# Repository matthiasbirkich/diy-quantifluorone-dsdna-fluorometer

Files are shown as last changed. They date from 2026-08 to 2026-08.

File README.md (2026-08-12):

## eDNA Workshop 2026 — Start Here

**Workshop participants:** 
You do not need to navigate the repository structure to get started.

### Start the Workshop

➡️ **[Start the Workshop](docs/markdown/SUMMARY.md)**

The online documentation guides you step by step through the workshop,
from the introduction and instrument assembly to software installation,
calibration, dsDNA measurement, quality control, and troubleshooting.
For sequential reading, use the chapter navigation provided in the
documentation.

### 📘 Complete Workshop Booklet

The complete workshop documentation is also available as a PDF for

offline use, printing, or download:

➡️ **[Download the complete Workshop Booklet (PDF)](00_DIY-QuantiFluorONE_Workshop_Handbook.pdf)**

The PDF is approximately 30 MB and may not be previewed directly by GitHub.

Downloading the file is therefore recommended.

### Repository contents

The folders in this repository contain the hardware files, software,
Calibration Suite, validation data, references, and editable documentation
used to reproduce the project.

The workshop booklet is the primary guide for assembly, software installation,
basic operation, calibration, quality control, dsDNA measurement, validation,
and troubleshooting.

It guides participants through:

1. instrument overview and measurement principle;
2. safety and laboratory preparation;
3. hardware and assembly;
4. software installation;
5. basic operation and menu navigation;
6. calibration and data transfer;
7. dsDNA measurement;
8. calibration, results, and quality control;
9. validation and analytical performance; and
10. troubleshooting and workshop review.

The folders in this repository contain the source files, hardware documentation,
software, calibration tools, validation data, references, and editable workshop
documentation used to reproduce the project.

## About the project

The **DIY-QuantiFluorONE-dsDNA-Fluorometer**, abbreviated **DIY-QFO**, is an
independently developed portable fluorometer for fluorometric quantification
of double-stranded DNA (**dsDNA**).

The instrument is designed for use with the **Promega QuantiFluor® ONE dsDNA
System** and combines:

- an **Adafruit PyBadge** as controller, display, and user interface;
- one **TSL2591** fluorescence sensor positioned at 90° to the excitation axis;
- an **ioRodeo fixed-current radial 16 mA LED board**;
- a 485 nm excitation LED;
- Neemoo Ex470BP-40 and Em532BP-40 optical band-pass filters;
- a modified 3D-printed optical sample holder derived from concepts used by
  **DIYNAFLUOR** and the **ioRodeo fluorometer tube-holder project**; and
- modified firmware derived from the open-source **ioRodeo Open Colorimeter
  Plus** project.

The modular optical design allows LEDs, filters, sample holders, and detector
settings to be adapted for other fluorescence-based analytical applications,
provided that the modified configuration is appropriately calibrated and
evaluated.

## Citation and archived release

The archived release associated with the Open Validation work is:

**DIY-QuantiFluorONE-dsDNA-Fluorometer v1.0.3**  
Zenodo DOI: https://doi.org/10.5281/zenodo.21909959

The associated methodological preprint is:

**Birkicht, M. (2026). Beyond the Black Box: From Open Hardware to Open Validation in Analytical Science.**  
Zenodo DOI: https://doi.org/10.5281/zenodo.21910043

## Workshop context

This repository and the accompanying workshop booklet were prepared for the
**eDNA Workshop 2026** within the **STABLE Project (2025–2027), Higher
Education Partnership for a Sustainable Blue Economy**.

The workshop uses the DIY-QFO as an open and reproducible platform for
introducing fluorometric dsDNA quantification, instrument construction,
calibration, quality control, and analytical evaluation.

The instrument is intended for **research, teaching, development, and workshop
measurements**. It is not intended for clinical diagnostic use.

## Documentation

The complete workshop documentation is available in several forms:

- **Workshop Booklet (PDF)** — primary document for workshop participants;
- `workshop_booklet/` — Quarto source used to generate the booklet;
- `docs/` — project documentation and figures;
- `references/` — bibliography and project source/provenance records.

For workshop participation, the PDF booklet is the recommended starting point.
Participants do not need to navigate the complete repository during the
practical exercises.

## Repository map

The principal project directories are:

- **`bom/`** — bill of materials and component information;
- **`docs/`** — project documentation and figures;
- **`hardware/`** — mechanical CAD models, PCB files, wiring information, and
  hardware documentation;
- **`references/`** — bibliography and source/provenance records;
- **`software/`** — PyBadge bootloader, CircuitPython, and the supported
  QuantiFluorONE firmware release;
- **`tools/`** — Calibration Suite and supporting analytical utilities;
- **`validation/`** — analytical validation datasets, processed data, and
  evaluation scripts;
- **`workshop_booklet/`** — Quarto sources for the workshop booklet.

This structure separates hardware, software, analytical tools, validation
evidence, references, and documentation while maintaining traceability between
the documented instrument and the files required to reproduce it.

## Optical architecture

The DIY-QFO uses one TSL2591 fluorescence sensor positioned **at 90°** to the
excitation axis.

The documented configuration uses:

- 485 nm excitation LED;
- Neemoo Ex470BP-40, 8 × 8 × 1 mm excitation filter;
- Neemoo Em532BP-40, 8 × 8 × 1 mm emission filter; and
- Promega E4941 thin-walled 0.5 mL PCR tubes.

Fluorescence emitted by the stained dsDNA sample passes through the emission
filter and is detected by the TSL2591.

The project-defined visible analytical signal is:

\[
VIS = FULL - IR
\]

and the blank-corrected fluorescence response is used for calibration and
concentration calculation.

## Calibration and analytical performance

The firmware supports an on-instrument two-point calibration and import of a
compatible multipoint calibration.

Routine operation uses a two-point calibration consisting of a reagent blank
and a nominal 400 ng/µL lambda-DNA standard.

Under the tested configuration and assay conditions, method performance was
evaluated over an operational range of:

**0–400 ng/µL dsDNA**

The validation study showed close agreement with a Promega Quantus Fluorometer
used as an independent external comparator.

The project currently uses approximately:

- **LOD: 8 ng/µL**
- **LOQ: 24 ng/µL**

on the original-sample concentration basis.

Detailed calibration procedures, quality-control requirements, statistical
evaluation, validation results, and limitations are documented in the workshop
booklet and under `validation/`.

## Software

The documented software configuration is:

- **PyBadge UF2 bootloader:** 3.15.0
- **Adafruit CircuitPython:** 9.1.1
- **QuantiFluorONE firmware:** QF1-1.0.0-rc2

The supported firmware package is stored under:

`software/quantifluorone_firmware/`

The repository follows a **one instrument — one supported firmware release**
policy for the documented workshop configuration.

## Safety and intended use

The DIY-QuantiFluorONE-dsDNA-Fluorometer is intended as a research, teaching,
development, and workshop instrument.

It is not a medical device and must not be used for:

- clinical diagnostic decisions;
- patient testing;
- therapeutic decisions;
- forensic conclusions; or
- other regulated diagnostic applications.

Users are responsible for following the safety instructions supplied with all
reagents, DNA standards, batteries, electronic components, laboratory equipment,
and consumables.

## Reproducibility and source records

Project-specific source and provenance records are maintained in:

- `references/references.bib`
- `references/hardware_sources.yml`
- `references/source_register.csv`
- `references/standards_register.md`

Component-specific source files, licences, and attribution information are
retained with the corresponding hardware and software documentation where
applicable.

## Citation

Citation metadata are maintained in [`CITATION.cff`](CITATION.cff).

Please use the citation information associated with the corresponding project
release when referencing the DIY-QuantiFluorONE-dsDNA-Fluorometer.

## License and third-party material

Original project material in this repository is released under the
[MIT License](LICENSE), unless otherwise stated.

Third-party software, hardware designs, documentation, and other incorporated
or referenced materials remain subject to their respective original licenses
and attribution requirements.

See the component-specific license files, source records, and documentation
for details.

## Trademark and affiliation notice

**Promega**, **QuantiFluor**, and **Quantus** are trademarks or registered
trademarks of Promega Corporation or its affiliates.

The DIY-QuantiFluorONE-dsDNA-Fluorometer is an independent DIY project. It is
not an official Promega product and is not presented as being endorsed,
certified, manufactured, or supported by Promega Corporation.

References to the Promega QuantiFluor® ONE dsDNA System and Promega Quantus™
Fluorometer identify the reagent system and commercial comparison instrument
used in the documented project.

## Acknowledgements

The project builds upon concepts, source code, mechanical designs, and
documentation from open-source projects including:

- **ioRodeo Open Colorimeter Plus**
- **ioRodeo fluorometer tube holder**
- **DIYNAFLUOR**
- **Adafruit CircuitPython**
- **PySpectrometer2**

The modified mechanical parts and their integration into the
DIY-QuantiFluorONE-dsDNA-Fluorometer were developed collaboratively by
**Dipl.-Ing. Matthias Birkicht** and **Florian Bock, 3D-Haven, Bremerhaven,
Germany**.

Complete references, licences, modification notes, and attribution information
are maintained in the project documentation and source records.

## Contact and project context

**Project author:** Dipl.-Ing. Matthias Birkicht

**eDNA Workshop 2026:** with Dr. Achim Meyer

**Workshop context:** STABLE Project (2025–2027), *Higher Education Partnership
for a Sustainable Blue Economy*

For technical details, reproducibility information, and source attribution,
consult the workshop booklet and the documentation contained in this repository.

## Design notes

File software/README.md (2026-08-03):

# Software

This directory contains the three software components required for the current
DIY-QuantiFluorONE-dsDNA-Fluorometer build:

```text
software/
├── bootloader/                   PyBadge UF2 bootloader files
├── circuitpython/                CircuitPython runtime
└── quantifluorone_firmware/      one supported device-firmware release
```

## Supported versions

- PyBadge bootloader: 3.15.0
- CircuitPython: 9.1.1
- QuantiFluorONE device firmware: QF1-1.0.0-rc2 stable

The main repository intentionally presents one current QuantiFluorONE firmware
release. Earlier development versions remain traceable through Git history,
tags, or GitHub releases rather than as parallel installation choices in this
directory.

Installation order:

1. update the bootloader only when required;
2. install CircuitPython 9.1.1 when required;
3. back up and empty `CIRCUITPY`;
4. copy the complete contents of the extracted stable RC2 release to the root of
   `CIRCUITPY`.

See `docs/markdown/07_software_installation.md`.

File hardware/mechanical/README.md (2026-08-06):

# Mechanical Components

This directory contains all mechanical CAD models required to build the
DIY-QuantiFluorONE-dsDNA-Fluorometer.

The optical components are modified versions derived from the open-source
DIYNAFLUOR project.

The PyBadge enclosure and cover are modified versions derived from the
ioRodeo Open Colorimeter Plus project.

## Optical Module

- A_Main_Body_modified
- B_Excitation_Housing_modified
- C_Emission_Housing_modified
- D_Emission_Baffle
- E_LED_Board_holder_thin
- E_LED_Board_holder_alternative
- F_Cover_Fluorometer_Optics

The filenames correspond directly to the engraved letters on the printed
parts used throughout the workshop documentation.

## PyBadge Enclosure

- pybadge_enclosure_v1r4
- pybadge_cover_v1r4

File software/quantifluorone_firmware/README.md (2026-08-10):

# QuantiFluorONE device firmware

## Current supported release

```text
QuantiFluorONE_Firmware_1.0.0-rc2-stable.zip
```

This archive is preserved unchanged as the tested firmware release for the
current instrument build. Do not replace it with a shortened, cleaned, or
repacked derivative.

## Clean installation

1. Back up the complete existing `CIRCUITPY` drive.
2. Enter CircuitPython safe mode with the slow reset double-click.
3. Delete the complete contents of `CIRCUITPY`.
4. Extract the stable RC2 ZIP on the computer.
5. Open the extracted `QuantiFluorONE_Firmware_1.0.0-rc2-stable` folder.
6. Copy all files and folders **inside** that folder to the root of the empty
   `CIRCUITPY` drive.
7. Do not copy the enclosing release folder itself.
8. Safely eject and restart the device.
9. Confirm `QuantiFluorONE v1.0 RC2` on the display.

The multipoint calibration used for quantitative measurements must correspond to the validated calibration workflow described in this repository. Verify the calibration identity, working range, concentration basis, and status before measuring samples.

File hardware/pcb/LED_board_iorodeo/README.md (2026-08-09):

# Upstream source: ioRodeo fixed-current radial LED board

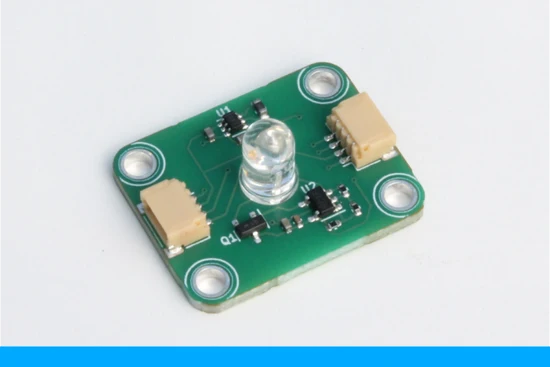
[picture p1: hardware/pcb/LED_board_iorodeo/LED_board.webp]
ioRodeo Fixed-Current Radial LED Board


- Project: i-control LED

- Board: Fixed-current radial LED board

- Installed revision: ver_0p1_rev_3

- Repository: https://github.com/iorodeo/i_control_led

- Source format: KiCad

- Licence: CC BY 4.0 (see `license/CC-BY-4.0.txt`)

- Variant: `fixed/5V_regulator/radial_16mA`

- Installed revision: `ver_0p1_rev_3`

- Production path: <https://github.com/iorodeo/i_control_led/tree/main/fixed/5V_regulator/radial_16mA/production/ver_0p1_rev_3>

- License supplied with this package: Creative Commons Attribution 4.0 International

This repository package contains the KiCad schematic and board files, Gerber/drill files, JLCPCB BOM and CPL files.

The radial wavelength-specific LED is installed separately on the back of the board. The board is a fixed-current board and is not an addressable I²C device.

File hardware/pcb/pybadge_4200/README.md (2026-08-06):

# Upstream source record — Adafruit PyBadge

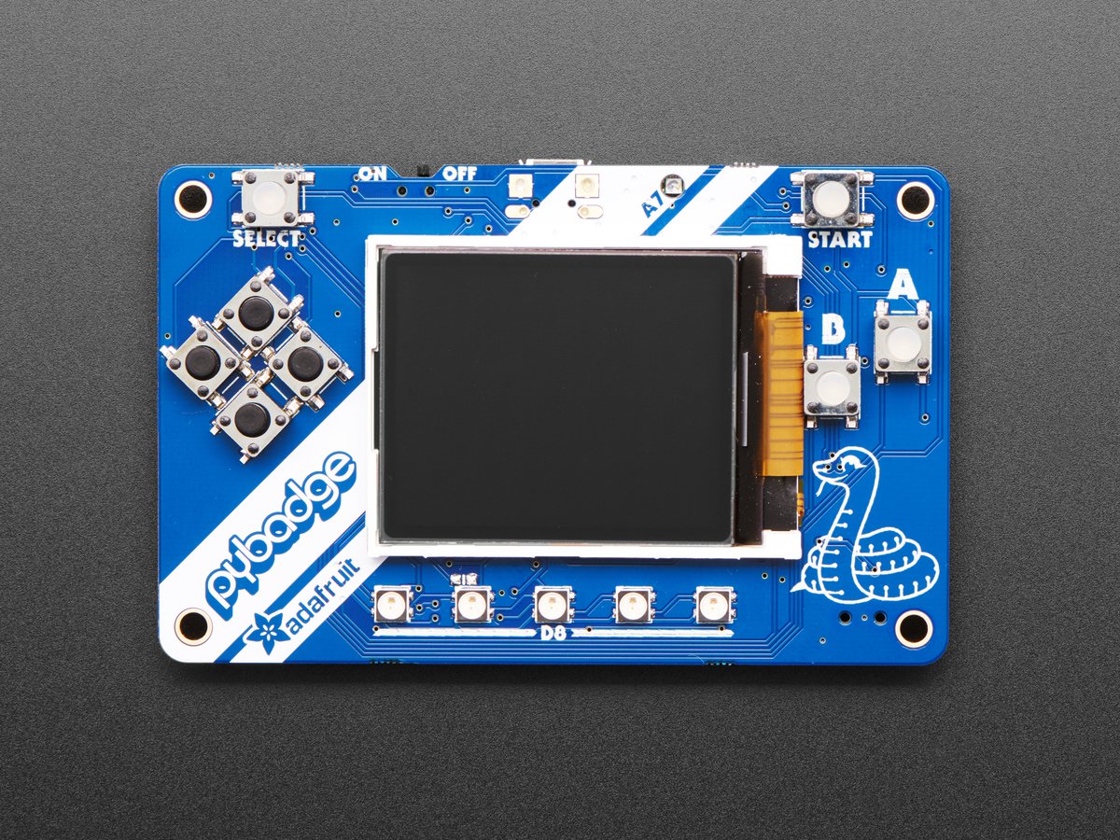
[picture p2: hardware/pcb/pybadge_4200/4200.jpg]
Adafruit PyBadge


- Product: Adafruit PyBadge
- Product ID: 4200
- Repository: https://github.com/adafruit/Adafruit-PyBadge-PCB
- Guide/downloads: https://learn.adafruit.com/adafruit-pybadge/downloads
- Source format: EagleCAD schematic and board layout
- Archive commit identifier: `992e322d5b4b0b9a2b60a809ba2ebaa2b0cfe090`
- Licence: Creative Commons Attribution-ShareAlike 3.0 Unported, as included in
  `eagle/license.txt`
  
## Adafruit PyBadge PCB

<a href="http://www.adafruit.com/products/4200"><br/>
Click here to purchase one from the Adafruit shop</a>

PCB files for the Adafruit PyBadge. 

Format is EagleCAD schematic and board layout
* https://www.adafruit.com/product/4200

### Description

What's the size of a credit card and can run CircuitPython, MakeCode Arcade or Arduino? That's right, its the **Adafruit PyBadge!** We wanted to see how much we could cram into a 3 3⁄8 × 2 1⁄8 inch rounded rectangle, to make an all-in-one dev board with a lot of possibilities, and this is what we came up with.

The PyBadge is a compact board, like we said, it's credit card sized. It's powered by our favorite chip, the ATSAMD51, with 512KB of flash and 192KB of RAM. We add 2 MB of QSPI flash for file storage, handy for images, fonts, sounds, or game assets.

On the front you get a 1.8" 160x128 color TFT display with dimmable backlight - we have fast DMA support for drawing so updates are incredibly fast. There's also 8 silicone-top buttons, they are clicky but have a soft button top so they're nice and grippy. The buttons are arranged to mimic a gaming handheld, with a d-pad, 2 menu-select buttons and 2 fire-action buttons. There's also 5 NeoPixel LEDs to dazzle or track activity.

On the back we have a full Feather-compatible header socket set, so you can plug in any FeatherWing to expand the capabilities of the PyBadge. There's also 3 STEMMA connectors - two 3-pin with ADC/PWM capability and one 4-pin that connects to I2C - you can use this for Grove sensors as well.

For built in sensors, there's a light sensor that points out the front, and a 3-axis accelerometer that can detect taps and free-fall. To make bleeps and bloops, there's a built in buzzer-speaker. [For projects where you need more volume, you can plug in one of our 8 ohm speakers](https://www.adafruit.com/product/3923).

[You can power the PyBadge from any of our LiPoly batteries, but we like this 400mAh one](https://www.adafruit.com/product/3898.) An on-off switch will save battery power when not in use. Or power from the Micro USB port - it will also charge up the battery if one is attached.

Now, how to program it? Well you've got a lot of options!

[MakeCode Arcade is the easiest to start for making games](https://arcade.makecode.com/), you can drag-and-drop blocks and load games over the disk-drive bootloader
[CircuitPython](https://circuitpython.org/board/pybadge/) lets you draw graphics, play wave files and print out text in any fonts - all in Python! There's tons of sensor support as well.
Arduino is low level, powerful, but a little more challenging. [You can use Adafruit Arcada](https://github.com/adafruit/Adafruit_Arcada) to interface with the hardware and it will abstract some of the nitty-gritty details like reading buttons for you.
Here's a list of everything you get

 * **ATSAMD51J19** @ 120MHz with 3.3V logic/power - 512KB of FLASH + 192KB of RAM
 * **2 MB of SPI Flash** for storing images, sounds, animations, whatever!
 * **1.8" 160x128 Color TFT Display** connected to its own SPI port
 * **8 x Game/Control Buttons** with nice silicone button tops (these feel great)
 * **5 x NeoPixels** for badge dazzle, or game score-keeping
 * **Triple-axis accelerometer** (motion sensor)
 * **Light sensor**, reverse-mount so that it points out the front
 * **Built in buzzer mini-speaker**
 * **Mono Class-D speaker driver for** 4-8 ohm speakers, up to 2 Watts
 * LiPoly battery port with built in recharging capability
 * USB port for battery charging, programming and debugging
 * Two female header strips with Feather-compatible pinout so you can plug any FeatherWings in
 * JST ports for NeoPixels, sensor input, and I2C (you can fit I2C Grove connectors in here)
 * Reset button
 * On-Off switch

### License

Adafruit invests time and resources providing this open source design, please support Adafruit and open-source hardware by purchasing products from [Adafruit](https://www.adafruit.com)!

Designed by Limor Fried/Ladyada for Adafruit Industries.

Creative Commons Attribution/Share-Alike, all text above must be included in any redistribution. 
See license.txt for additional details.

The PyBadge may be purchased as an assembled module. The PCB source files are
included for open-hardware traceability and are not presented as a practical
workshop assembly route for the densely populated controller board.

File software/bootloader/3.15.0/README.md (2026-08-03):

# PyBadge UF2 bootloader 3.15.0

Included files:

- `update-bootloader-arcade_pybadge-v3.15.0.uf2`
- `bootloader-arcade_pybadge-v3.15.0.bin`

## Recommended workshop update file

Use the UF2 updater for the normal USB drag-and-drop workflow:

`update-bootloader-arcade_pybadge-v3.15.0.uf2`

1. Connect the PyBadge using a USB Micro data cable.
2. Enter the UF2 bootloader with a **fast double-click** of Reset.
3. Wait for `PYBADGEBOOT` or `BADGEBOOT` to appear.
4. Copy `update-bootloader-arcade_pybadge-v3.15.0.uf2` to that drive.
5. Wait for the board to restart.
6. Re-enter UF2 bootloader mode and verify version 3.15.0 in `INFO_UF2.TXT`.
7. Reinstall CircuitPython 9.1.1 afterwards.

## Raw binary archive

`bootloader-arcade_pybadge-v3.15.0.bin` is retained for open-science archiving
and technical recovery. **Do not copy this `.bin` file directly to
`PYBADGEBOOT` or `BADGEBOOT`.** It is not the normal workshop installation file.

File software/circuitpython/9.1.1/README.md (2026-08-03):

# CircuitPython 9.1.1 for Adafruit PyBadge

Included file:

`adafruit-circuitpython-pybadge-en_US-9.1.1.uf2`

Use the PyBadge UF2 bootloader drive (`PYBADGEBOOT` or `BADGEBOOT`) for
installation. Copy the UF2 file to the boot drive and wait for the board to
restart as `CIRCUITPY`.

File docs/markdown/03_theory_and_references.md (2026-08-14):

---
document-status: "Current"
validation-status: "Validated configuration"
date: "2026-08-14"
---

## Purpose and practical scope

Instrument qualification, assay calibration, method validation, and comparison with established instruments are complementary but distinct elements of analytical quality assurance. Throughout this project, the emphasis is placed on transparent documentation of the complete measurement chain rather than on comparison with a single commercial instrument.

This chapter provides the minimum theory needed to understand, calibrate, and use the DIY-QuantiFluorONE-dsDNA-Fluorometer in a workshop. It is not intended to be a complete textbook on fluorescence spectroscopy or analytical-method validation.

The instrument uses off-the-shelf optical and electronic components, one fluorescence sensor, a fixed 90° optical geometry, and the Promega QuantiFluor® ONE dsDNA assay. Quantitative results are obtained only after blank measurement and calibration. The current repository status and the analytical validation status must always be reported separately.

> **Workshop objective:** Prepare a reagent blank, standards, and unknown samples; measure the blank-corrected fluorescence response; apply a two-point or multipoint calibration; and interpret the result within the calibrated working range.

## Fluorescence in brief

A fluorophore absorbs excitation light and reaches an electronically excited state. Part of the absorbed energy is then emitted as fluorescence at a longer wavelength. The separation between the excitation and emission maxima is the **Stokes shift**.

For the QuantiFluor® ONE dsDNA dye, Promega specifies an excitation maximum of 504 nm and an emission maximum of 531 nm. The nominal Stokes shift is therefore about 27 nm [@promega_tm405].

Within a suitable working range, the fluorescence response increases with the amount of dye-bound dsDNA. The measured signal is also influenced by excitation intensity, filter transmission, sample-vessel geometry, dye binding, sensor settings, temperature, and sample matrix. At high concentrations, detector saturation, inner-filter effects, or dye-response nonlinearity may occur [@lakowicz2006; @valeur2012].

Important practical effects are:

- **Background:** signal from the reagent, tube, sensor, stray light, and sample matrix;
- **Quenching:** reduced fluorescence caused by molecular interactions or sample constituents;
- **Photobleaching:** signal loss caused by prolonged illumination;
- **Interference:** fluorescence or absorption from contaminants, extraction reagents, RNA, ssDNA, proteins, salts, or solvents.

These effects are controlled primarily by using a matching reagent blank, identical tubes and geometry, consistent incubation and reading times, and calibration standards prepared in a suitable matrix.

## Optical architecture

The optical path is fixed by the 3D-printed holder:

```text
485 nm nominal radial LED
        ↓
Neemoo Ex470BP-40 excitation filter
        ↓
Promega E4941 thin-walled 0.5 mL PCR tube
        ↓
QuantiFluor® ONE dye–dsDNA fluorescence
        ↓  at 90° to the excitation axis
Neemoo Em532BP-40 emission filter
        ↓
one Adafruit TSL2591 fluorescence sensor
```

The TSL2591 sensor axis is positioned **at 90°** to the excitation axis. This geometry reduces direct illumination of the sensor by the excitation beam. The geometry, tube position, filters, LED current, gain, and integration time are part of the calibration and must remain unchanged during a measurement series.

### Selection of the Optical Configuration

The optical configuration of the DIY-QuantiFluorONE-dsDNA-Fluorometer was selected to maximize excitation efficiency while minimizing stray excitation light reaching the detector.

The 485 nm excitation LED closely matches the excitation spectrum of the Promega QuantiFluor® ONE dsDNA dye. The Ex470BP-40 excitation filter narrows the LED spectrum, while the Em532BP-40 emission filter efficiently suppresses scattered excitation light and transmits the fluorescence emission around 530 nm.

The spectral relationship between the excitation source, optical filters and fluorescence spectra is illustrated in Figure 3.1.

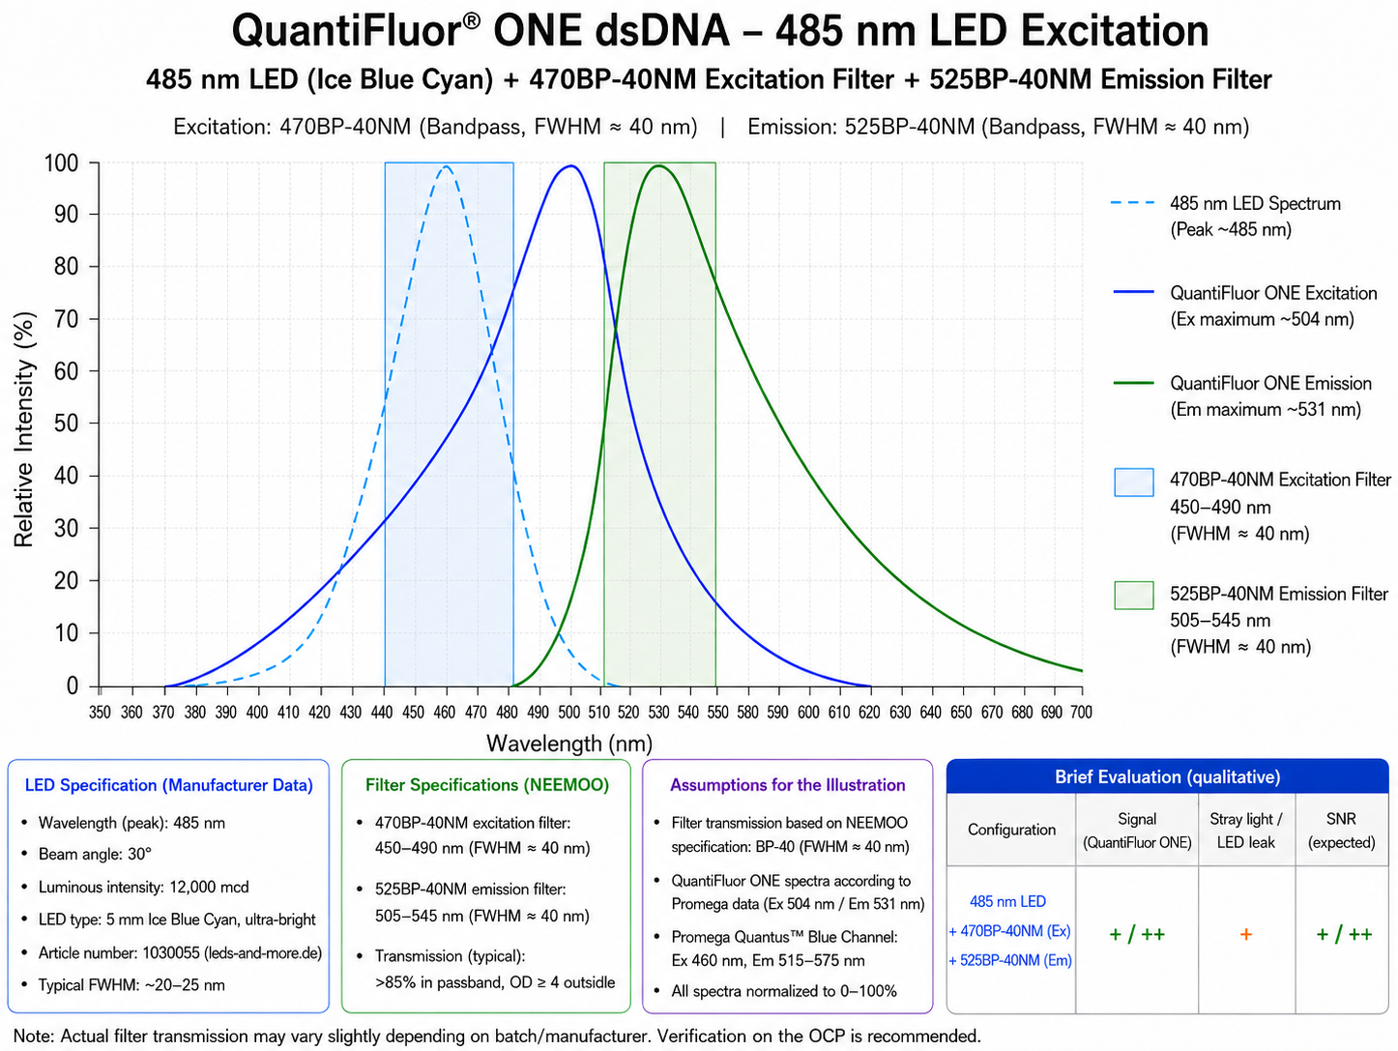
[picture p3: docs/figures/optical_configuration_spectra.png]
Spectral compatibility of the optical configuration


**Figure 3.1** Spectral compatibility of the 485 nm excitation LED, Ex470BP-40 excitation filter, Em532BP-40 emission filter and the QuantiFluor® ONE dsDNA fluorescence system. The overlap illustrates the optical basis of the DIY-QuantiFluorONE-dsDNA-Fluorometer.

The same design principle can be applied to other fluorescence assays by selecting appropriate LEDs, optical filters, cuvette holders and calibration models.

### Installed optical and electronic components

| Component | Installed configuration | Practical role |
|---|---|---|
| Excitation LED | 5 mm radial 485 nm “Ice Blue/Cyan” LED; 30°; 12,000 mcd; 3.2 V; article 1030055 | Excites the dye–dsDNA complex |
| LED control board | ioRodeo `radial_16mA` fixed-current LED board, `ver_0p1_rev_3`, 16 mA | Provides a defined fixed current for the excitation LED; not an addressable I²C device |
| Excitation filter | Neemoo Ex470BP-40 | Selects the useful blue excitation band and reduces longer-wavelength LED emission |
| Sample vessel | Promega thin-walled 0.5 mL PCR tube, Cat. No. E4941 | Defines the assay volume and optical geometry |
| Emission filter | Neemoo Em532BP-40 | Passes the green fluorescence band and suppresses excitation light |
| Sensor | Adafruit TSL2591 High Dynamic Range Digital Light Sensor, Product ID 1980, I²C address `0x29` | Measures the filtered fluorescence signal |
| Multiplexer | Adafruit PCA9546 four-channel STEMMA QT/Qwiic I²C multiplexer, project inventory Product ID 5664, address `0x70` | Selects the connected I²C channels |
| Controller | Adafruit PyBadge, Product ID 4200 | Runs the CircuitPython firmware and displays and stores results |
| Cabling | STEMMA QT/Qwiic JST SH four-pin cables and SparkFun PRT-15109 Qwiic–Grove adapter | Connects the PyBadge, multiplexer, LED board, and sensor |

The PyBadge-based firmware and hardware arrangement build on the open ioRodeo Open Colorimeter Plus ecosystem [@iorodeo_ocp_firmware; @iorodeo_led_board]. Component identities and connections are documented by the corresponding Adafruit and SparkFun sources [@adafruit_tsl2591; @adafruit_pca9546; @adafruit_pybadge; @sparkfun_prt15109].

### Filter verification

The supplier provides the nominal filter designation and percentage-transmittance information [@neemoo_filters]. The actual installed filter specimens were additionally checked with the project’s DIY spectrometer based on Leslie Wright’s PySpectrometer2 project [@wright_pyspectrometer2].

The project measurements were normalized to the maximum of each curve and were used to verify the passband position and shape:

- Ex470BP-40: approximate half-maximum interval 450–490 nm;
- Em532BP-40: approximate half-maximum interval 518–555 nm.

The measurements confirm the intended spectral separation but are not used as an absolute calibration of filter transmittance.

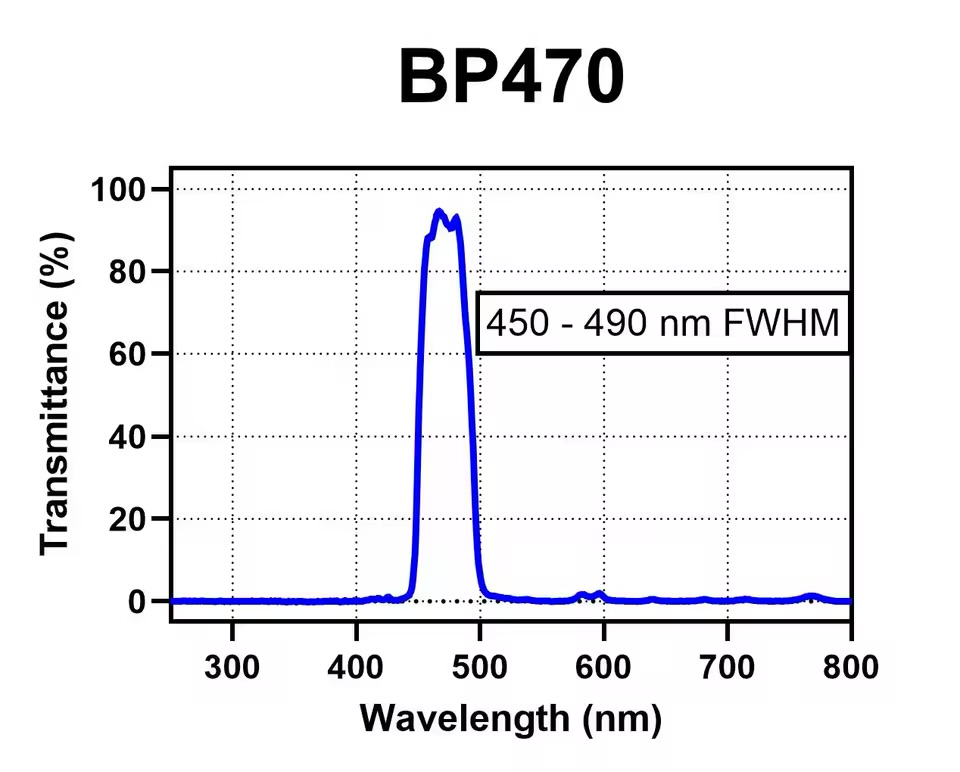
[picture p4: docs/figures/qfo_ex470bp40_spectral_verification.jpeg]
Spectral verification of the installed Neemoo Ex470BP-40 excitation filter. The project measurement was normalized to its maximum; the approximate half-maximum interval was 450–490 nm.


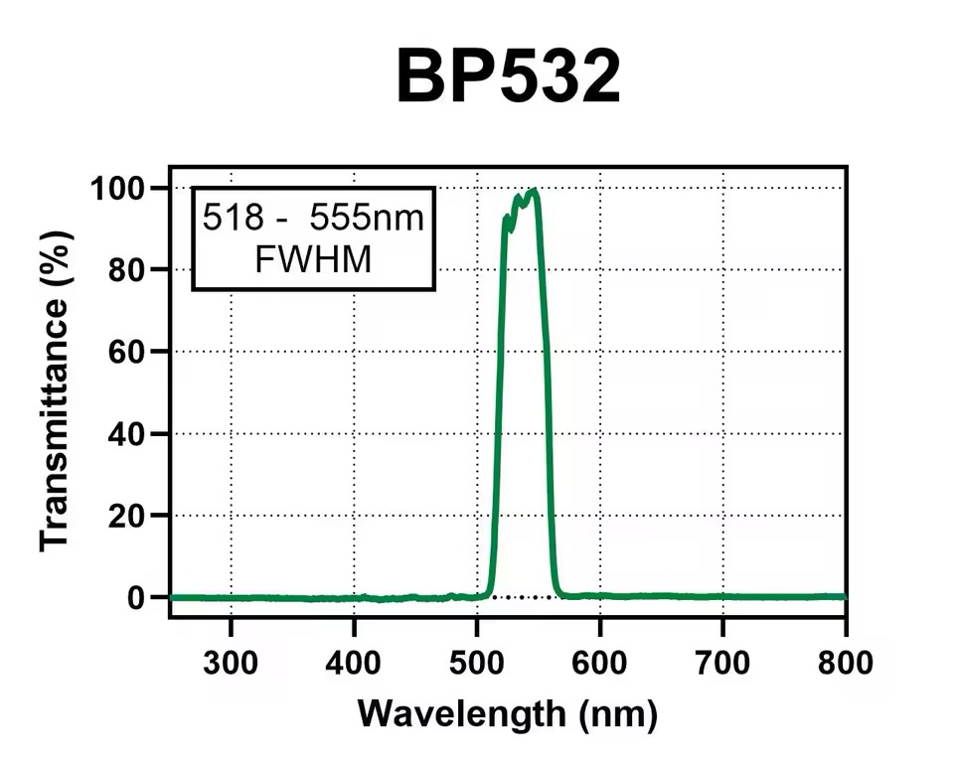
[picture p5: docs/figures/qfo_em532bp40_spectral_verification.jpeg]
Spectral verification of the installed Neemoo Em532BP-40 emission filter. The project measurement was normalized to its maximum; the approximate half-maximum interval was 518–555 nm.


## Signal formation and blank correction

The TSL2591 provides a full-spectrum channel and an infrared channel. The firmware calculates a project-defined visible signal for each reading:

$$
VIS_i = \max(FULL_i - IR_i, 0)
$$

One measurement cycle consists of three technical sensor readings. Their mean is used as the cycle result:

$$
\overline{VIS}=\frac{1}{3}\sum_{i=1}^{3}VIS_i
$$

The reagent blank contains the QuantiFluor® ONE reagent but no added dsDNA. The blank-corrected response is:

$$
RFU=\overline{VIS}_{sample}-\overline{VIS}_{blank}
$$

RFU means **relative fluorescence unit**. It is an instrument-dependent response, not an SI unit. Signed RFU values are retained in the raw data. A negative value indicates that the measured sample response was below the stored blank response; it must not be interpreted as a negative physical DNA concentration.

A new blank should be measured when the reagent lot, tube type, optical arrangement, sensor settings, temperature conditions, or measurement session changes.

## dsDNA quantification with QuantiFluor® ONE

The QuantiFluor® ONE dsDNA System is an add-and-read fluorescent assay for purified dsDNA. Promega specifies 504 nm excitation, 531 nm emission, and a nominal range of 0.2–400 ng dsDNA input. The kit includes QuantiFluor® ONE Lambda DNA at 400 µg/mL as a calibration material [@promega_tm405].

The project uses:

```text
1 µL sample or standard + 200 µL QuantiFluor® ONE reagent
= 201 µL physical total volume
```

Promega recommends thin-walled 0.5 mL PCR tubes, thorough mixing without bubbles, five minutes of incubation at room temperature protected from light, and careful pipetting of the small sample volume [@promega_tm405].

### $\lambda$-DNA standards

Promega supplies $\lambda$-DNA as the dsDNA calibration material for the QuantiFluor® ONE assay. The stock concentration specified by the manufacturer is 400 µg/mL, which is exactly equivalent to 400 ng/µL. Because the fluorometer reports DNA concentrations in ng/µL and the assay range is expressed in the same unit, 400 ng/µL is used throughout this booklet for consistency [@promega_tm405].

Record the supplier, product, lot, stock concentration, dilution medium, preparation date, and storage conditions of all calibration standards. Use fresh low-concentration dilutions where practical. Promega recommends thorough mixing of the standard and assay reagent; vortex well while avoiding persistent air bubbles.

Promega also notes that a dsDNA standard with a molecular size similar to that of the unknown DNA can improve comparability. Therefore, $\lambda$-DNA is a practical and well-defined workshop calibration standard, but differences in DNA fragment size and sample matrix may remain sources of bias [@promega_tm405].

Lambda DNA is a linear dsDNA molecule containing 48,502 bp. Using an approximate average molecular mass of 650 Da per base pair, intact $\lambda$-DNA has a molecular mass of approximately 31.5 MDa. Thus, 1 ng of intact $\lambda$-DNA corresponds to approximately 0.032 fmol, or about 32 fmol per µg.

The DNA mass contained in a selected volume is calculated from its mass concentration:

$$m\;(\mathrm{ng}) = c\;(\mathrm{ng}/\mu\mathrm{L}) \times V\;(\mu\mathrm{L})$$

The corresponding molar amount can then be estimated from the DNA mass and the representative fragment length:

$$n_{\mathrm{DNA}}\;(\mathrm{fmol}) \approx \frac{m\;(\mathrm{ng}) \times 10^{6}}{650 \times L\;(\mathrm{bp})}$$

Combining both steps gives the direct conversion from a measured DNA concentration:

$$n_{\mathrm{DNA}}\;(\mathrm{fmol}) \approx \frac{c\;(\mathrm{ng}/\mu\mathrm{L}) \times V\;(\mu\mathrm{L}) \times 10^{6}}{650 \times L\;(\mathrm{bp})}$$

where $c$ is the DNA concentration in ng/µL, $V$ is the selected DNA volume in µL, and $L$ is the representative DNA fragment length in base pairs.

For the supplied Promega $\lambda$-DNA standard, 1 µL of the 400 ng/µL stock contains:

$$m = 400\;\mathrm{ng}/\mu\mathrm{L} \times 1\;\mu\mathrm{L} = 400\;\mathrm{ng}$$

For intact 48,502-bp $\lambda$-DNA:

$$n_{\mathrm{DNA}} \approx \frac{400 \times 10^{6}}{650 \times 48{,}502} \approx 12.7\;\mathrm{fmol}$$

Thus, 1 µL of the 400 ng/µL $\lambda$-DNA stock contains 400 ng DNA but only approximately 12.7 fmol of intact $\lambda$-DNA molecules. The same DNA mass represents a much larger molar amount when the DNA is present as shorter fragments.

**PCR context:** In the downstream PCR workflow used for this workshop, approximately 100 fmol DNA template is targeted, with 80 fmol regarded as the minimum acceptable input. This requirement cannot be inferred directly from the fluorometrically measured concentration in ng/µL: conversion to fmol additionally requires the volume of DNA used and an appropriate representative fragment length.

For example, 100 fmol corresponds to approximately 9.8 ng at 150 bp, 32.5 ng at 500 bp, and 65 ng at 1000 bp.

Getting started with instrument operation, use of the Calibration Suite, sample-list editing, and the dsDNA measurement protocol is covered in Chapters 6–8.

## Analytical validity, reference methods, and open measurement chains

Instrument qualification, assay calibration, and method validation are related but distinct tasks. A fluorometer can be checked for properties such as linear response, wavelength suitability, detector response, sensitivity, and day-to-day stability without treating another fluorometer as an absolute reference. General fluorescence-quality guidance likewise distinguishes instrument characterization and performance verification from the validation of the analytical method itself.[^fluorometry-qa]

For dsDNA quantification, a commercial fluorometer is therefore useful as a **comparison instrument**, but agreement with one commercial instrument is not the only possible evidence of analytical validity. A stronger validation strategy combines several independent lines of evidence: assigned or independently characterized DNA standards, repeatability and linearity studies, blank behaviour, recovery, LOD/LOQ, and comparison with an analytically independent method.

For sufficiently pure dsDNA at concentrations suitable for absorbance measurement, UV photometry at 260 nm provides such an independent comparison principle through the Beer–Lambert relationship and an accepted DNA-specific mass-extinction convention. Fluorometric and photometric DNA determinations are not chemically identical measurements: absorbance at 260 nm responds to total UV-absorbing nucleic-acid material and other absorbing contaminants, whereas the QuantiFluor® ONE assay is designed to respond preferentially to dsDNA. Promega therefore notes that concentrations obtained by fluorescence and by optical-density measurements may differ because the two methods measure different properties of the sample [@promega_tm405]. Agreement should consequently be evaluated on clean, well-characterized dsDNA standards rather than assumed for arbitrary biological extracts.

This distinction is particularly useful for open-science instrumentation. The analytical evidence need not form a hierarchy in which an open instrument is considered valid only because it reproduces the result of a proprietary instrument. Instead, the DIY-QuantiFluorONE can be evaluated within an **open measurement chain**: reference or assigned DNA materials define the sample, photometric determination provides an independent physical-chemical comparison where applicable, open fluorometers such as DIYNAFLUOR provide reproducible peer systems, and established commercial instruments provide continuity with routine laboratory practice.

The objective is therefore not to designate one instrument as the universal reference, but to demonstrate that the complete measurement procedure is transparent, reproducible, and consistent with independent analytical evidence within stated uncertainty and applicability limits. This is also why the project retains raw signals, calibration metadata, blank statistics, model diagnostics, and validation data rather than reporting only a final concentration.

[^fluorometry-qa]: See Resch-Genger U, Hoffmann K, Nietfeld W, et al. *How to improve quality assurance in fluorometry: fluorescence-inherent sources of error and suited fluorescence standards*. Journal of Fluorescence. 2005;15:337–362. doi:10.1007/s10895-005-2630-3; and DeRose PC, Resch-Genger U. *Recommendations for Fluorescence Instrument Qualification: The New ASTM Standard Guide*. Analytical Chemistry. 2010;82(5). These works discuss instrument qualification, linearity, spectral response, wavelength accuracy, sensitivity, and performance verification as elements of quantitative fluorescence quality assurance.

## Calibration

Calibration links the blank-corrected fluorescence response to an assigned dsDNA concentration or DNA mass. The linear model used by the project is:

$$
y=a+bx
$$

where $y$ is RFU, $x$ is the selected concentration or mass basis, $a$ is the intercept, and $b$ is the slope. For an unknown sample:

$$
\hat{x}=\frac{y-a}{b}
$$

The calibration basis and unit must be stored with the calibration. The firmware normally reports the original-sample concentration in ng/µL and also records the corresponding in-assay concentration.

### Two-point calibration

The two-point workflow uses a reagent blank and one known standard. After blank correction, the working intercept is zero:

$$
b=\frac{RFU_{standard}}{x_{standard}}
$$

$$
x_{sample}=\frac{RFU_{sample}}{b}
$$

Two-point calibration is fast and suitable for a workshop routine when the assay response is known to be linear in the selected range. It does not by itself test linearity or provide a residual-based assessment across the range.

### Multipoint calibration

Multipoint calibration uses several concentration levels and replicate measurements. Calibration Suite 7.3 can calculate ordinary least squares (OLS) and compare it with weighted models (`1/c`, `1/c²`, and `1/s²`). It also displays residuals, confidence bands, prediction bands, recovery, and model-comparison statistics.

The current PyBadge firmware imports accepted OLS calibration data. Model selection and diagnostics are performed in Calibration Suite 7.3 before the calibration JSON is transferred to the instrument.

DIN 38402-51:2017-05 is used as a reference for linear calibration concepts. The repository cites the standard but does not reproduce protected standard text [@din38402_51].

> **Practical rule:** Do not report a sample quantitatively outside the calibrated range. Dilute or re-prepare the sample and measure it again.

## LOD and LOQ

The limit of detection (LOD) and limit of quantification (LOQ) depend on the selected procedure, calibration, blank variability, and dataset. They are not fixed properties of the dye or sensor alone.

### Two-point firmware estimate

For an active two-point calibration, the firmware can measure ten independently prepared reagent blanks. Each blank is measured as one complete three-reading cycle. The sample standard deviation of the ten blank-cycle means is used:

$$
LOD_{estimate}=\frac{3s_{blank}}{b}
$$

$$
LOQ_{estimate}=\frac{10s_{blank}}{b}
$$

These are transparent blank-based estimates for workshop and instrument evaluation. They are not presented as a complete implementation of every procedure in DIN 32645.

### Multipoint calculation in Calibration Suite 7.3

For multipoint calibration, Calibration Suite 7.3 implements the indirect calibration-curve calculation documented in the software as the DIN 32645 method summarized in CLB1. The calculation uses the residual standard deviation, slope, Student-$t$ factors, calibration design, significance level, the selected quantification factor $k$, and the number of future determinations. The LOQ is solved iteratively.

DIN 32645:2008-11 is cited as the relevant standard for decision, detection, and quantification limits under repeatability conditions [@din32645]. A formal claim of conformity requires a documented comparison of the software implementation with the licensed standard and the defined validation protocol.

Always report LOD and LOQ together with the calibration ID, method, unit, significance level, $k$ factor, number of calibration levels and replicates, and software version.

## Reference projects and commercial comparison

| System | Relevant role in this project | Main distinction |
|---|---|---|
| ioRodeo Open Colorimeter Plus | Open hardware and CircuitPython reference platform | General open optical-instrument platform used as a technical base |
| DIYNAFLUOR | Open-source reference for an inexpensive 90° TSL2591 nucleic-acid fluorometer | Developed primarily for Qubit assays; uses two-point calibration and off-the-shelf components |
| DIY-QuantiFluorONE | Workshop instrument described here | QuantiFluor® ONE assay, Ex470BP-40, Em532BP-40, one TSL2591 at 90°, two-point and imported multipoint calibration |
| Promega Quantus™ | Commercial reference instrument | Blue excitation peak 470 nm, blue emission band 510–580 nm, solid-state detector, and manufacturer-defined calibration workflow |

DIYNAFLUOR demonstrates that a practical nucleic-acid fluorometer can be constructed from readily available parts, a 3D-printed optical head, a 90° optical path, and a TSL2591 sensor [@anderson_diynafluor; @traulab_diynafluor]. The DIY-QuantiFluorONE design follows the same practical open-hardware philosophy but uses a different controller, LED board, filter set, assay, and calibration workflow.

Promega specifies the Quantus™ blue channel with a 470 nm excitation peak, excitation wavelengths up to 495 nm, and an emission range of 510–580 nm [@promega_tm396]. These ranges are compatible with the QuantiFluor® ONE assay and provide a useful commercial reference. Direct statements about bias, precision, or agreement require measurements of the same standards on both instruments.

## Practical validity conditions and limitations

A calibration remains valid only while the measurement configuration remains unchanged. Recalibrate or verify the calibration after changing any of the following:

- LED, LED current, excitation filter, or emission filter;
- tube type, holder, insertion depth, or optical alignment;
- TSL2591 gain, integration time, sensor board, or multiplexer channel;
- reagent formulation or lot;
- sample and reagent volumes;
- concentration basis or blank preparation.

During workshop measurements:

1. Use the same tube type for blank, standards, and unknowns.
2. Keep tube orientation and insertion depth consistent.
3. Avoid bubbles, droplets above the liquid level, fingerprints, and scratches.
4. Mix and incubate all tubes consistently and protect them from light.
5. Measure a reagent blank before samples.
6. Use standards that bracket the expected sample concentration.
7. Repeat or dilute samples outside the calibrated range.
8. Retain raw FULL, IR, VIS, blank, RFU, calibration ID, and result data.

The method is intended for research, teaching, and workshop use. It is not a clinical diagnostic method. The supplier’s nominal assay range is not automatically the validated working range of the assembled DIY instrument.

## Workshop take-away

The practical measurement chain is:

```text
Prepare blank and standards
→ incubate consistently
→ measure one TSL2591 at 90°
→ calculate VIS and blank-corrected RFU
→ apply the selected calibration
→ check range, LOD/LOQ, and validity conditions
→ save the raw and calculated data
```

The practical implementation of these analytical concepts, including calibration acceptance, quality control, uncertainty evaluation, and routine decision criteria, is described in Chapter 9.
---

⬅️ Previous Chapter: [Safety](02_safety.md)

📖 [Documentation Summary](SUMMARY.md)

➡️ Next Chapter: [Hardware and Assembly](04_hardware_and_assembly.md)

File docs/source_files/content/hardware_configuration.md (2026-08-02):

# Defined Hardware Configuration

This file is reusable source content for the theory chapter, BOM notes, and assembly documentation.

| Component | Defined project configuration | Function |
|---|---|---|
| Excitation LED | 5 mm radial 485 nm “Ice Blue/Cyan”; 30°; 12,000 mcd; 3.2 V; article 1030055 | Excites the QuantiFluor® ONE dye–dsDNA complex |
| LED board | ioRodeo `i_control_led`, I²C, SMD0603 production `ver_0p1_rev_2`, 16 mA, STEMMA QT | Controls LED operation |
| Excitation filter | Neemoo Ex470BP-40, installed | Defines the excitation band |
| Sample vessel | Promega thin-walled 0.5 mL PCR tube, Cat. No. E4941 | Holds blank, standards, and samples |
| Optical geometry | One TSL2591 sensor at 90° to the excitation axis | Reduces direct excitation light at the detector |
| Emission filter | Neemoo Em532BP-40, installed | Passes fluorescence and suppresses excitation light |
| Sensor | Adafruit TSL2591, Product ID 1980, PCB revision 2023-10-24, STEMMA QT, I²C `0x29` | Measures the fluorescence signal |
| Multiplexer | Adafruit PCA9546 four-channel STEMMA QT/Qwiic multiplexer, project inventory Product ID 5664, I²C `0x70` | Selects the LED and sensor I²C channels |
| Controller | Adafruit PyBadge, Product ID 4200 | Runs CircuitPython firmware and user interface |
| Adapter | SparkFun Qwiic–Grove cable, 100 mm, PRT-15109 | Connects PyBadge I²C/Grove to Qwiic/STEMMA QT |
| Internal cables | STEMMA QT/Qwiic JST SH four-pin cables | Connects multiplexer, LED board, and sensor |

## Electrical connection overview

```text
Adafruit PyBadge 4200
        │ I²C/Grove
SparkFun PRT-15109 adapter
        │ Qwiic/STEMMA QT
Adafruit PCA9546 multiplexer, 0x70
        ├── configured channel → ioRodeo 16 mA LED board
        └── configured channel → Adafruit TSL2591, 0x29
```

## Calibration-critical configuration

The following are part of the calibration: LED and current, excitation and emission filters, sample vessel and insertion geometry, sensor position, TSL2591 gain and integration time, reagent and lot, assay volumes, and blank preparation.

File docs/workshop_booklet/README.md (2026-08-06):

# Workshop booklet and PDF generation

This directory contains the canonical **Quarto book project** for the workshop booklet.

## Source-of-truth rule

- Files under `docs/workshop_booklet/` are the editable source of truth.
- Files under `docs/markdown/` are synchronized Markdown reading copies.
- Do not edit the Markdown copy independently and then expect the QMD source to update.
- Only files listed in `_quarto.yml` are part of the active booklet.

## Active structure

1. Introduction and Learning Objectives
2. Safety and Laboratory Requirements
3. Theory and References
4. Hardware and Assembly
5. Getting Started: Basic Operation and Menu Navigation
6. Calibration Suite and Data Transfer
7. Software Installation
8. Measurement Protocol
9. Calibration, Results, and Quality Control
10. Validation and Performance
11. Troubleshooting
12. Workshop Exercises and Checklists
13. References

Appendices are stored under `appendices/`.

## Render commands

From `docs/workshop_booklet/` run:

```bash
quarto render
```

To render only HTML:

```bash
quarto render --to html
```

To render only PDF:

```bash
quarto render --to pdf
```

Quarto writes the output to `_book/`.

## Editing workflow

1. Edit the relevant `.qmd` file.
2. Keep the chapter title in YAML front matter; do not add a duplicate numbered H1 heading.
3. Use `##` for main sections and `###` for subsections.
4. Add or remove active chapters only by editing `_quarto.yml` at the same time.
5. Regenerate the corresponding Markdown copy under `docs/markdown/`.
6. Render and review HTML before PDF.
7. Commit source, synchronized Markdown, and configuration changes together.

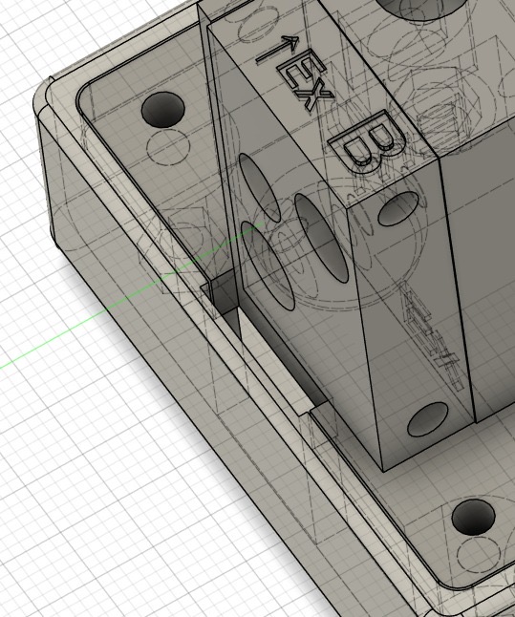
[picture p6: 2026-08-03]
docs/figures/optical_module_closeup_cad.jpeg

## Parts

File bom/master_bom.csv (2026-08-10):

Category | Qty | Item | Supplier | Part_or_Article | Function | Notes
Controller | 1 | Adafruit PyBadge | Adafruit | 4200 | Main controller and UI | CircuitPython 9.1.1 workflow
I2C distribution | 1 | Adafruit PCA9546 multiplexer | Adafruit | 5664 | I2C bus multiplexer | Address 0x70
Detector | 1 | Adafruit TSL2591 STEMMA QT | Adafruit | 1980 | Fluorescence detector | Address 0x29; only one sensor used
LED driver | 1 | ioRodeo fixed-current radial LED board | ioRodeo | radial_16mA ver_0p1_rev_3 | Drives excitation LED | Fixed nominal current 16 mA; no I2C address
Excitation source | 1 | 5 mm Ice Blue/Cyan LED | LEDs and More | 1030055 | Excitation source | 485 nm; 30°; 12000 mcd; 3.2 V
Excitation filter | 1 | Neemoo Ex470BP-40 | Neemoo | Ex470BP-40 | Excitation filtering | 8 x 8 x 1 mm
Emission filter | 1 | Neemoo Em532BP-40 | Neemoo | Em532BP-40 | Emission filtering | 8 x 8 x 1 mm
Sample vessel | as required | Promega E4941 thin-walled 0.5 mL PCR tube | Promega | E4941 | Sample container | Workshop tube format
Cable | as required | STEMMA QT / Qwiic JST SH cable | Various | JST SH 4-pin | Power and I2C cabling | Exact lengths still to be documented
Adapter | 1 | SparkFun Qwiic-to-Grove adapter cable | SparkFun | PRT-15109 | Adapter between board ecosystems | Upstream adapter used from PyBadge side
Mechanical | 1 | PyBadge enclosure set | Project CAD | v1r4 | Enclosure for controller | STEP files included
Mechanical | 1 | 0.5 mL PCR-tube holder with integrated optics | Project CAD | confirmed | Optical alignment and tube positioning | upload ok
Mechanical | 1 | Light shield | Project CAD | pending | Blocks ambient light | upload OK
Power | 1 | USB Micro cable | Generic | USB Micro | Programming power and charging | Known-good data cable recommended
Power | 0 or 1 | 3.7 V LiPo battery | Generic | 400 mAh | Portable operation | Optional status until final confirmation
Fastener | 4 | M2.5 x 20 screw | Generic | M2.5x20 | Fastens PyBadge cover to enclosure | Use with matching M2.5 nut
Fastener | 4 | M2.5 nut | Generic | M2.5 | Matches PyBadge-cover screw | Current assembly quantity
Fastener | 4 | M3 x 20 screw | Generic | M3x20 | Fastens PCR-tube holder to enclosure | Use with matching M3 nut
Fastener | 4 | M3 nut | Generic | M3 | Matches PCR-tube-holder screw | Current assembly quantity

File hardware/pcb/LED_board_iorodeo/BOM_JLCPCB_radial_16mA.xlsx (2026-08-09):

Comment | Designator | Footprint | LCSC Part #（optional） | Qty | supplier
10V 10μF Ceramic Capacitor | C1,C2 C4 | 0402 | C315248 | 3
16V 100nF Ceramic Capacitor | C3 | 0402 | C60474 | 1
4-Pin Connector, JST SM04B-SRSS-TB | J1 ,J2 | SMD,P=1mm | C160404 | 2
4.7μH Inductor ±20%, 440mOhm | L1 | 0603 | C114862 | 1
MMBT5551LT1G Bipolar Transistor, 600mA NPN | Q1 | SOT-23 | C41095 | 1
10Ω ±1% Resistor | R1 | 0402 | C854481 | 1
30kΩ ±1% Resistor | R2 | 0402 | C138008 | 1
1kΩ ±1% Resistor | R3 | 0402 | C144789 | 1
TPS61222DCKR, boost converter, fixed 5V | U1 | SOT-363-6(SC-70-6) | C116461 | 1
LMV321 Operational Amplifier | U2 | SOT-23-5 | C7972 | 1 | TI

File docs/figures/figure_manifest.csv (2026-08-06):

Figure_ID | Relative_path_from_docs_figures | Caption | Status | Source | Notes
fig-ch03-01 | source/ch03/optical_configuration_spectra.png
fig-ch04-01 | photos/ch04/assembled_instrument_front.jpg | Assembled prototype, front view | Included | Project photograph supplied 2026-08-03 | Displayed reading is not analytical validation data
fig-ch04-02 | cad/ch04/pybadge_enclosure_cad.jpeg | PyBadge enclosure CAD overview | Included | Project CAD screenshot
fig-ch04-03 | cad/ch04/optical_module_overview_cad.jpeg | Optical module mounted on base | Included | Project CAD screenshot
fig-ch04-04 | cad/ch04/optical_module_closeup_cad.jpeg | Optical holder close-up | Included | Project CAD screenshot
fig-ch04-05 | cad/ch04/light_shield_part_cad.jpeg | Light-shield part CAD view | Included | Project CAD screenshot
fig-ch04-06 | source/ch04/qfo_optical_geometry.svg | 90-degree optical geometry | Generated in package | Project diagram
fig-ch04-07 | source/ch04/qfo_electronics_overview.svg | Electronics and I2C overview | Generated in package | Project diagram
fig-ch04-08 | photos/ch04/open_instrument_wiring.jpg | Open instrument with complete wiring | Included | Project photograph
fig-ch04-09 | photos/ch04/excitation_side_led_filter.jpg | LED and Ex470BP-40 installation | Included | Project photograph
fig-ch04-10 | photos/ch04/detection_side_filter_sensor.jpg | Em532BP-40 and one TSL2591 installation | Included | Project photograph
fig-ch04-11 | photos/ch04/measuring_setup.jpg | Complete measurement setup used throughout the workshop with electronic shield | Included | Project photograph

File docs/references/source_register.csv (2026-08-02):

source_id | source_type | title | author_or_organisation | version_or_date | url_or_path | role_in_repository | evidence_status | accessed
SRC-001 | manufacturer manual | QuantiFluor® ONE dsDNA System Technical Manual | Promega | TM405; revised 10/22 | https://www.promega.com/resources/protocols/technical-manuals/101/quantifluor-one-dsdna-system-protocol/ | Assay principle, wavelengths, range, lambda DNA, protocol, tubes, interferences | primary | 2026-08-02
SRC-002 | manufacturer manual | Quantus™ Fluorometer Operating Manual | Promega | TM396; revised 11/24 | https://www.promega.com/resources/protocols/technical-manuals/101/quantus-fluorometer-operating-manual-protocol/ | Commercial instrument comparison | primary | 2026-08-02
SRC-003 | open-source repository | Open Colorimeter Plus firmware | ioRodeo | current repository | https://github.com/iorodeo/open_colorimeter_plus_firmware | Hardware and CircuitPython reference platform | primary | 2026-08-02
SRC-004 | open-source repository | i_control_led I²C radial LED board | ioRodeo | ver_0p1_rev_2, SMD0603, 16 mA | https://github.com/iorodeo/i_control_led/tree/main/i2c/5V_regulator/SMD0603_i2c/production/ver_0p1_rev_2 | Installed LED board | primary | 2026-08-02
SRC-005 | supplier listing | Neemoo optical band-pass filters | Neemoo / AliExpress | item 1005010613836251 | https://de.aliexpress.com/item/1005010613836251.html | Filter identity, nominal designations and supplier transmittance information | vendor; volatile | 2026-08-02
SRC-006 | open-source repository | PySpectrometer2 | Leslie Wright | current repository | https://github.com/leswright1977/PySpectrometer2 | Basis of the project DIY spectrometer used for filter-band verification | primary | 2026-08-02
SRC-007 | project measurement | Ex470BP-40 spectral verification | QuantiFluorONE project | 2026 project measurement | docs/figures/source/qfo_ex470bp40_spectral_verification.jpeg | Verification of passband position and shape; normalized to curve maximum | project evidence | 2026-08-02
SRC-008 | project measurement | Em532BP-40 spectral verification | QuantiFluorONE project | 2026 project measurement | docs/figures/source/qfo_em532bp40_spectral_verification.jpeg | Verification of passband position and shape; normalized to curve maximum | project evidence | 2026-08-02
SRC-009 | component page | TSL2591 Product ID 1980 | Adafruit Industries | PCB revision 2023-10-24 documented by project | https://www.adafruit.com/product/1980 | Installed fluorescence sensor | primary | 2026-08-02
SRC-010 | component guide | PCA9546 4-channel I²C multiplexer | Adafruit Industries | project inventory Product ID 5664 | https://learn.adafruit.com/adafruit-pca9546-4-channel-i2c-multiplexer/overview | Multiplexer architecture and default address | primary | 2026-08-02
SRC-011 | component page | Adafruit PyBadge Product ID 4200 | Adafruit Industries | Product ID 4200 | https://www.adafruit.com/product/4200 | Controller | primary | 2026-08-02
SRC-012 | component page | Qwiic Cable—Grove Adapter, 100 mm | SparkFun Electronics | PRT-15109 | https://www.sparkfun.com/qwiic-cable-grove-adapter-100mm.html | Controller-to-Qwiic adapter | primary | 2026-08-02
SRC-013 | preprint | DIYNAFLUOR | Anderson et al. | bioRxiv 2024.12.16.626200 | https://doi.org/10.1101/2024.12.16.626200 | Open low-cost fluorometer comparison; not peer reviewed | preprint | 2026-08-02
SRC-014 | open-source repository | DIYNAFLUOR | Trau Lab | current repository | https://github.com/traulab/DIYNAFLUOR | Code, BOM, build files and instructions | primary | 2026-08-02
SRC-015 | standard | DIN 38402-51:2017-05 | DIN | 2017-05 | https://www.dinmedia.de/de/norm/din-38402-51/272448891 | Linear calibration reference | licensed standard required | 2026-08-02
SRC-016 | standard | DIN 32645:2008-11 | DIN | 2008-11 | https://www.dinmedia.de/de/norm/din-32645/110729574 | LOD and LOQ reference | licensed standard required | 2026-08-02
SRC-017 | software | Open Fluorometer Calibration Suite | QuantiFluorONE project | v7.2 Stable | calibration_suite/v7.2-stable/ | Implemented calibration, model comparison, LOD/LOQ and JSON export | project software | 2026-08-02

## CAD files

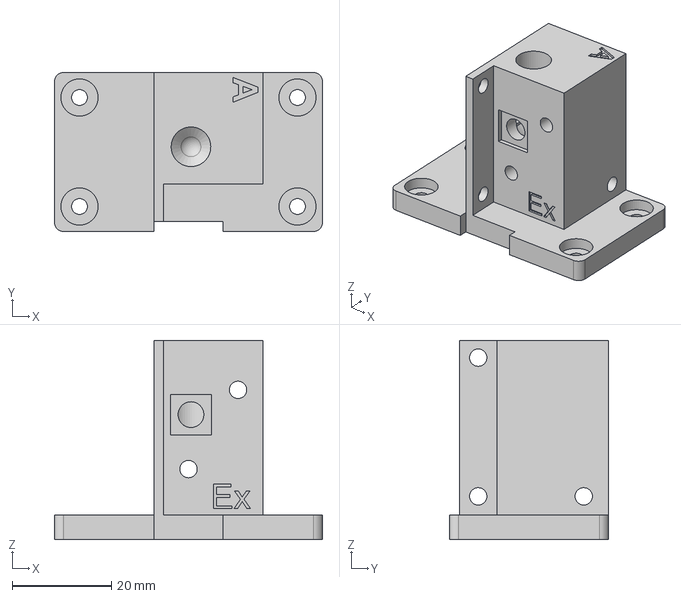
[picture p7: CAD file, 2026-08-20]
hardware/mechanical/step/A_Main_Body_modified_v13.step
54.1 x 32.1 x 40.3 mm

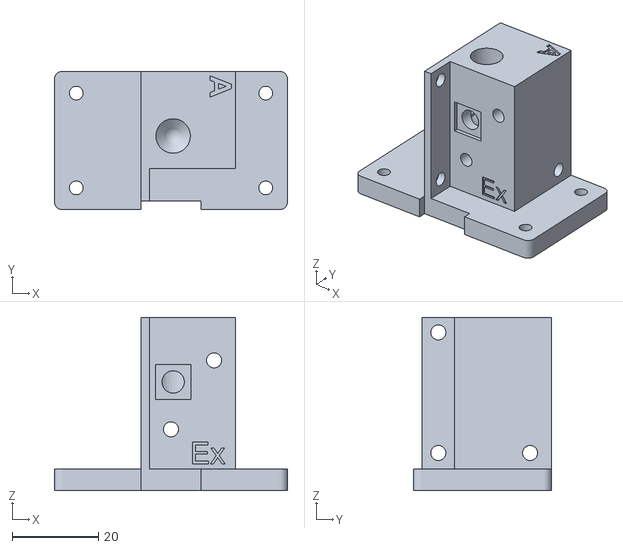
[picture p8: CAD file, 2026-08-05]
hardware/mechanical/stl/A_Main_Body_modified.stl
54.1 x 32.1 x 40.2

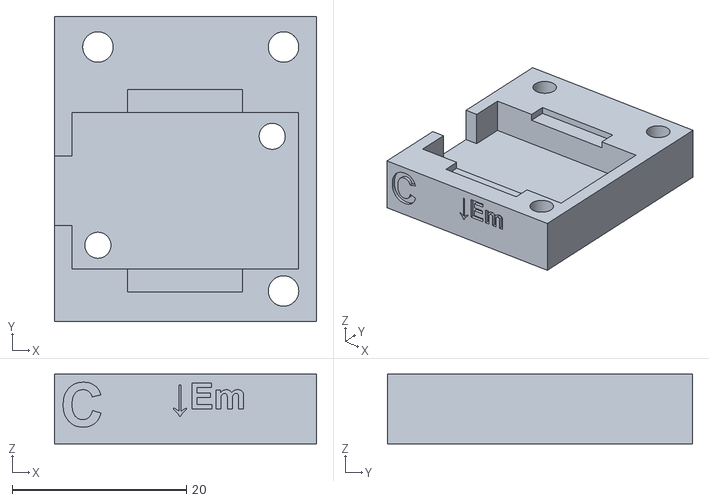
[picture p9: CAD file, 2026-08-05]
hardware/mechanical/stl/C_Emission_Housing_modified.stl
30.1 x 35.0 x 8.00

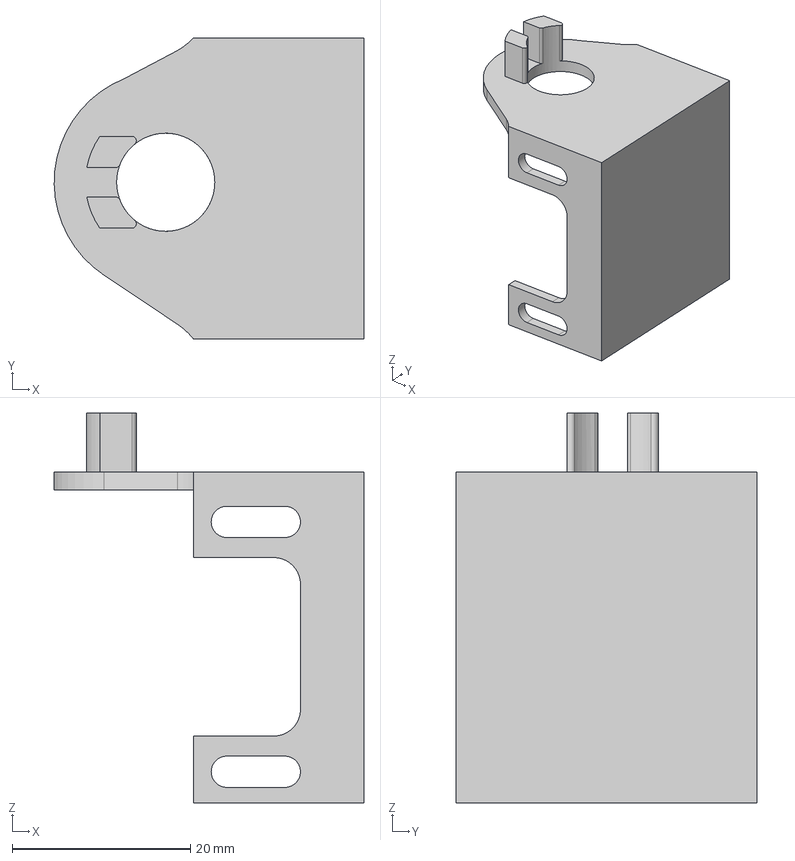
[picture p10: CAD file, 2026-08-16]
hardware/mechanical/step/E_LED Board + Vial Halter.step
34.7 x 33.7 x 43.7 mm

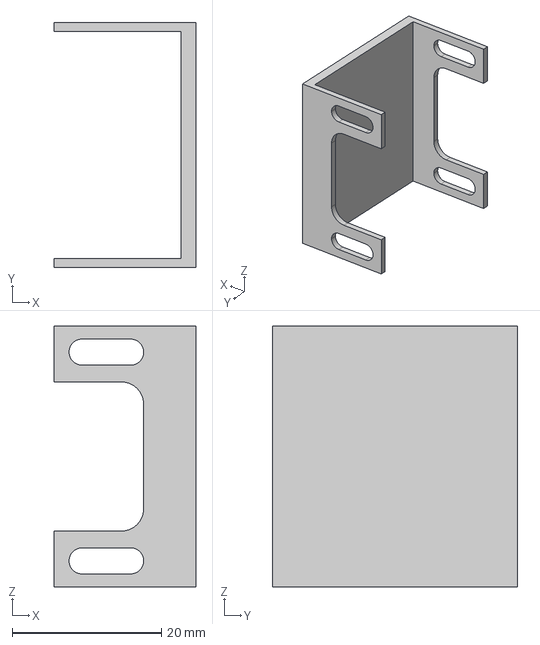
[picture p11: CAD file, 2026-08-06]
hardware/mechanical/step/E_LED_Board_holder_thin.step
19.0 x 32.8 x 35.0 mm

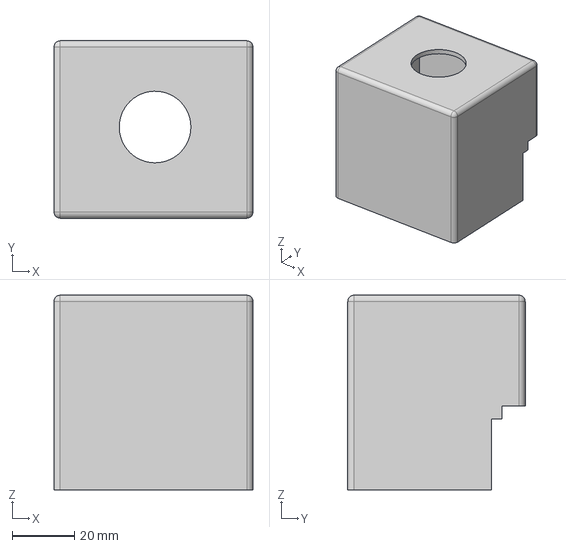
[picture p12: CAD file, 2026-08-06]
hardware/mechanical/step/F_Cover_Fluorometer_Optics.step
63.9 x 57.0 x 62.5 mm

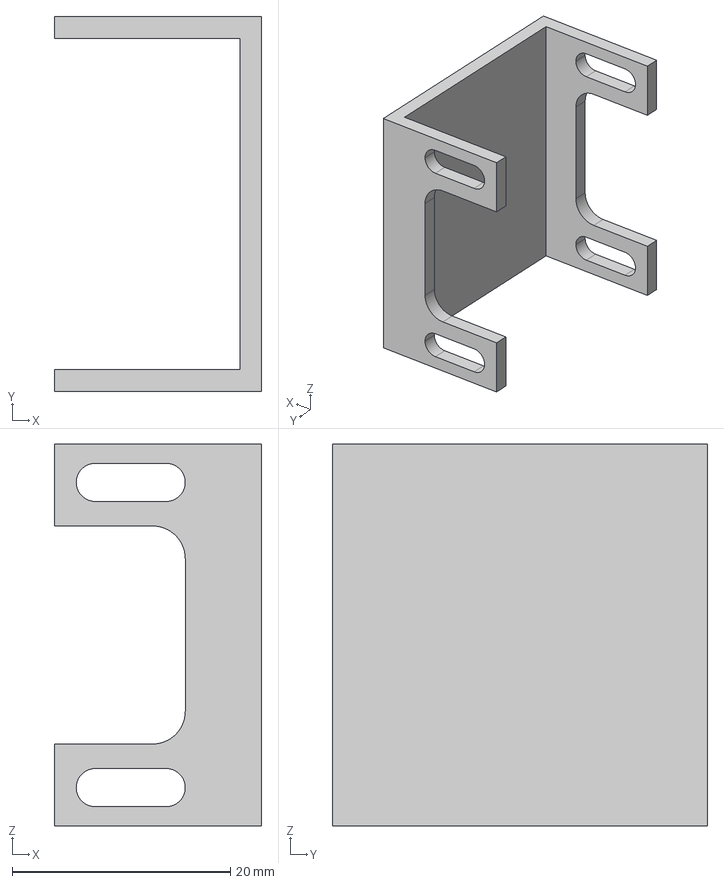
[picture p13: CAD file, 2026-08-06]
hardware/mechanical/step/E_LED_Board_holder_alternative.step
19.0 x 34.4 x 35.0 mm

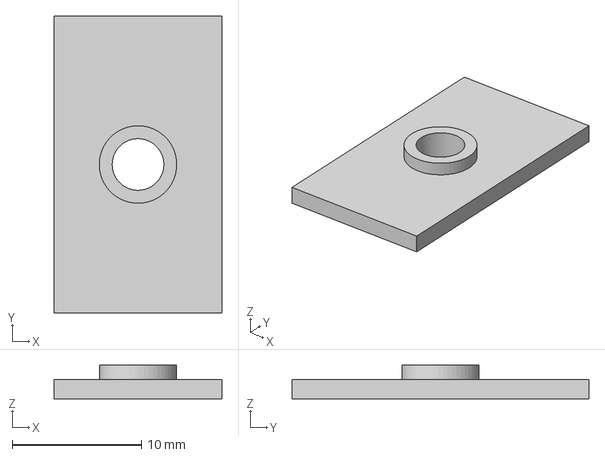
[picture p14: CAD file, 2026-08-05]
hardware/mechanical/step/D_Emission_Baffle.step
13.0 x 23.0 x 2.60 mm

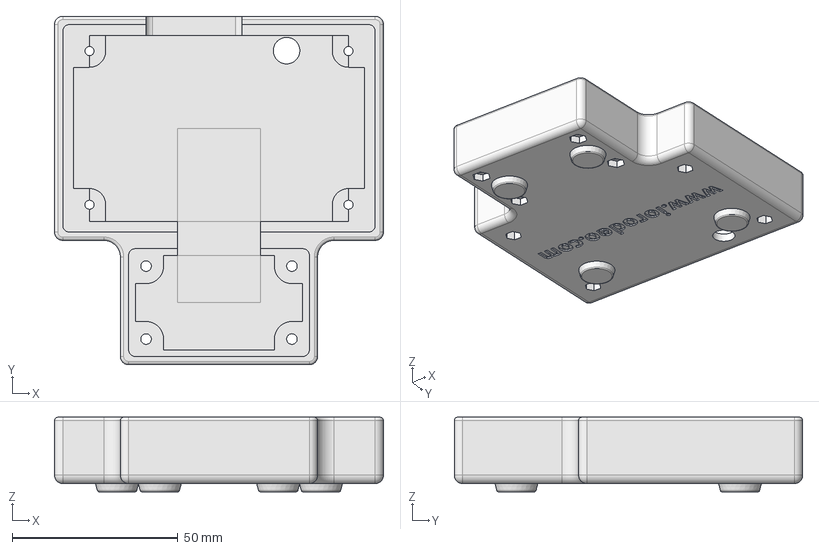
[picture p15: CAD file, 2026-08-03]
hardware/mechanical/step/colorimeter_enclosure_v1r4.step
99.2 x 105.1 x 22.5 mm

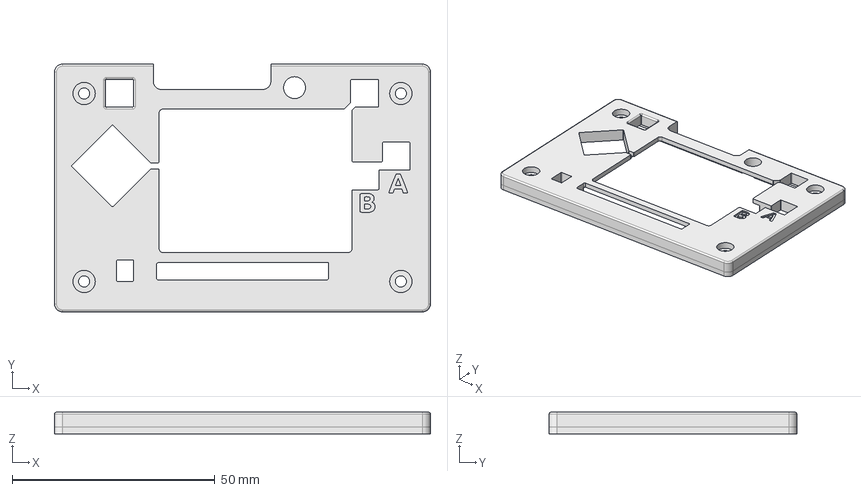
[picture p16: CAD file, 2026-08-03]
hardware/mechanical/step/pybadge_cover_v1r4.step
92.7 x 61.1 x 5.35 mm

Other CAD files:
hardware/mechanical/step/B_Excitation_Housing_modified.step
hardware/mechanical/step/C_Emission_Housing_modified_v3.step
hardware/mechanical/stl/B_Excitation_Housing_modified.step
hardware/mechanical/stl/B_Excitation_Housing_modified.stl
hardware/mechanical/stl/D_Emission_Baffle.stl
hardware/mechanical/stl/E_LED_Board_holder_alternative.stl
hardware/mechanical/stl/E_LED_Board_holder_thin.stl
hardware/mechanical/stl/F_Cover_Fluorometer_Optics.stl

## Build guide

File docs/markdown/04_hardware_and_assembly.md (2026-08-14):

---
document-status: "Current"
validation-status: "Validated configuration"
date: "2026-08-14"
---

## Purpose and workshop outcome

This chapter guides participants through the identification, assembly, inspection, and first hardware check of the DIY-QuantiFluorONE-dsDNA-Fluorometer. It is intended as a practical build guide rather than a comprehensive electronics or fluorescence textbook.

At the end of the workshop, the participant should be able to:

- identify every electronic, optical, and mechanical component;
- install the 485 nm excitation source and both optical filters;
- install the Promega E4941 tube holder and the single TSL2591 sensor;
- confirm that the detection axis is fixed at 90° to the excitation axis;
- connect the PyBadge, PCA9546 multiplexer, TSL2591, and fixed-current LED board;
- perform a pre-power inspection and a first hardware test;
- locate the source, CAD, PCB, Gerber, and assembly files needed to reproduce the instrument.

The instrument uses **one TSL2591 sensor only**. It does not use a second reference or transmission sensor.

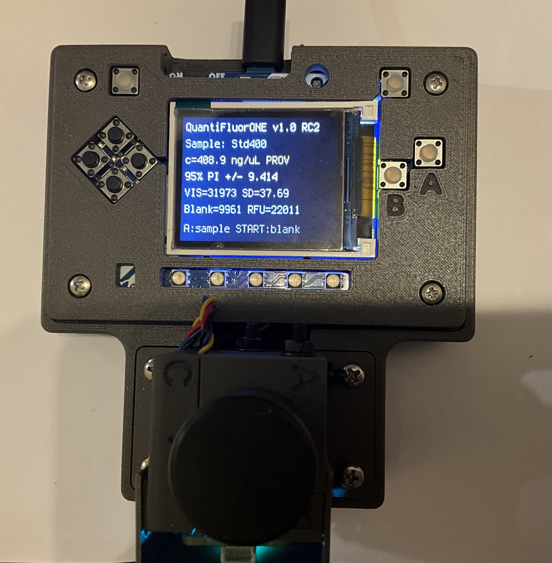
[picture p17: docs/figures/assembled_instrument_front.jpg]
Assembled DIY-QuantiFluorONE prototype during a firmware and display check. The displayed measurement is not presented as analytical validation data.


## Complete component overview and bill of materials

The machine-readable bill of materials is stored in `bom/master_bom.csv`. The core configuration is summarized below.

| Group | Component | Confirmed configuration | Quantity |
|---|---|---|---:|
| Controller | Adafruit PyBadge | Product ID 4200 | 1 |
| I²C distribution | Adafruit PCA9546 multiplexer | Product ID 5664; address `0x70` | 1 |
| Detector | Adafruit TSL2591 STEMMA QT | Product ID 1980; address `0x29` | 1 |
| LED driver | ioRodeo fixed-current radial LED board | `radial_16mA`, `ver_0p1_rev_3` | 1 |
| Excitation source | 5 mm Ice Blue/Cyan radial LED | 485 nm; 30°; 12,000 mcd; 3.2 V; article 1030055 | 1 |
| Excitation filter | Neemoo Ex470BP-40 | **8 x 8 x 1 mm**, installed | 1 |
| Emission filter | Neemoo Em532BP-40 | **8 x 8 x 1 mm**, installed | 1 |
| Sample vessel | Promega E4941 thin-walled 0.5 mL PCR tube | workshop sample tube | as required |
| Cabling | STEMMA QT / Qwiic JST SH four-pin cables | 10 cm | 1 |
| Cabling | STEMMA QT / Qwiic JST SH four-pin cables |  5 cm | 1 |
| Adapter | SparkFun Qwiic-to-Grove adapter cable | PRT-15109 | 1 |
| Mechanical assembly | 3D-printed PyBadge enclosure | STEP files included | 1 set |
| Optical assembly | 3D-printed tube and optics holder | step file | 1 |
| Light control | 3D-printed light shield | step file  | 1 |
| Programming and power | USB Micro cable | programming, power, and charging | 1 |
| Portable power | 3.7 V LiPo battery | 400 mAh; status optional| 0 or 1 |
| Portable power | 3.7 V LiPo battery | 1200 mAh; status optional| 0 or 1 |

The confirmed mounting fasteners are:

- four M2.5 x 20 screws with matching M2.5 nuts for fastening the PyBadge cover to the enclosure;
- four M3 x 20 screws with matching M3 nuts for fastening the PCR-tube holder to the enclosure.
- two M2 x 6 screws with matching nuts for emission filter holder C
- four M3 x 35 screws with matching M3 nuts for fastening the cuvette holder to the led-cover and parts A+B

Main electronic, optical, mechanical, and laboratory components used to assemble and operate the DIY-QuantiFluorONE-dsDNA-Fluorometer.

## Function of the components

### Electronic components

**Adafruit PyBadge.** The PyBadge is the controller and user interface. It provides the display, buttons, reset switch, on/off switch, USB Micro connection, LiPo connector, battery charging circuit, and the I²C interface used by the external modules. The documented software baseline for this project is CircuitPython 9.1.1.

**PCA9546 multiplexer.** The multiplexer divides the upstream I²C connection into four selectable downstream branches. Its address is `0x70`. The firmware scans the available multiplexer channels for the TSL2591 sensor, so a fixed downstream channel assignment is not required.

**TSL2591 sensor.** The TSL2591 detects light passing through the emission filter. Its address is `0x29`. Only one TSL2591 is installed, and its detection axis is mechanically fixed at 90° to the excitation axis.

**ioRodeo fixed-current LED board.** Revision `ver_0p1_rev_3` supplies a fixed nominal LED current of 16 mA. It is not an addressable I²C device. Its SDA and SCL conductors are pass-through connections, so the board must not be expected to appear in an I²C scan.

### Optical components

**485 nm LED.** The LED provides excitation light. Its radial package must be installed with the correct polarity and must be seated without bending the leads against the printed holder.

**Ex470BP-40 excitation filter.** This **8 x 8 x 1 mm** filter is positioned between the LED and sample tube. It limits the excitation spectrum before the light reaches the sample.

**Em532BP-40 emission filter.** This **8 x 8 x 1 mm** filter is positioned between the sample tube and TSL2591. It reduces direct excitation light and passes the fluorescence region used by the detector.

**Promega E4941 tube.** The thin-walled 0.5 mL PCR tube defines the sample container used by the mechanical holder. The tube must reach the mechanical stop reproducibly and must not be forced into the holder.

### Mechanical components

The printed parts perform four critical tasks:

1. locate the sample tube at a reproducible depth;
2. align the LED and excitation filter with the excitation axis;
3. align the emission filter and active TSL2591 area with the detection axis;
4. shield the optical path from room light and display light.

The holder establishes the 90° geometry mechanically.
The mechanical development of the optical sample holder also draws on the
open ioRodeo fluorometer tube-holder project. The original repository provides
FreeCAD design files for the fluorometer tube holder and is distributed under
the Creative Commons Attribution 4.0 International (CC BY 4.0) licence.

The DIY-QuantiFluorONE holder combines and adapts elements of these open
designs for the Promega E4941 thin-walled 0.5 mL PCR tube, the installed
8 × 8 × 1 mm optical filters, one TSL2591 sensor, and the project-specific
90° optical geometry [@anderson_diynafluor; @traulab_diynafluor] [@iorodeo_fluorometer_tube_holder]

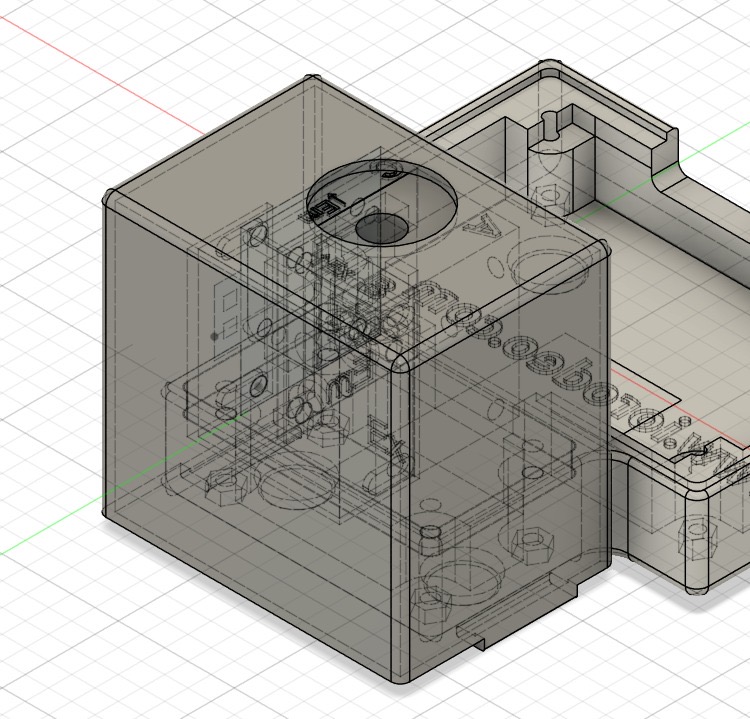
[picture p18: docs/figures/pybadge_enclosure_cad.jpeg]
CAD overview of the PyBadge enclosure and instrument base.


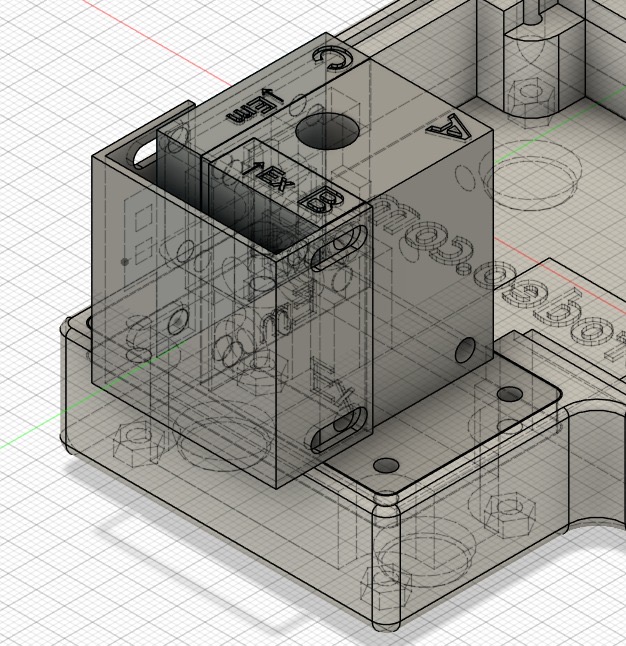
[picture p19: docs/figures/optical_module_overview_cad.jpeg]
CAD overview of the optical module mounted on the instrument base.


## Preparation and inspection of the 3D-printed parts

Before installing electronics or filters:

1. Compare every printed part with the CAD screenshots and file names.
2. Remove support material completely from tube, LED, filter, sensor, screw, and cable openings.
3. Check that no loose strands, curled edges, or partially detached layers can enter the optical path.
4. Inspect the tube bore for ridges that could scratch or jam an E4941 tube.
5. Insert an empty tube gently and confirm that it reaches the stop without excessive force.
6. Check the filter pockets with a clean **8 x 8 x 1 mm** test piece where possible.
7. Check that the LED board and TSL2591 can be inserted without bending the PCBs.
8. Hold the empty printed assembly against a bright lamp and mark any visible light leaks.
9. Clean all printed debris before bringing the optical filters near the holder.

Do not enlarge filter pockets with a power tool while the filters or electronics are installed. Fine manual correction is safer and easier to control.

## Installation of the LED and excitation filter

1. Disconnect USB and remove the LiPo battery if fitted.
2. Identify the LED anode and cathode from the component data and PCB markings.
3. Insert the 5 mm 485 nm LED into the ioRodeo radial LED board in the documented polarity.
4. Confirm that the LED body is straight and that its optical axis points through the excitation opening.
5. Solder only after checking orientation. Avoid prolonged heating of the LED leads.
6. Trim leads so that they cannot touch the enclosure or another conductor.
7. Handle the **8 x 8 x 1 mm** Ex470BP-40 by its edges. Do not touch the clear aperture.
8. Insert the filter into the excitation-filter pocket without twisting or forcing it.
9. Confirm that the filter fully covers the optical opening and cannot rattle into the tube chamber.
10. Install the Part B with two M3 x 40 screws and nuts
11. Install the 485 nm LED-board and the holder. Fix ist with 3M x 40 screws and nuts.

> **Check:** Looking from the LED side, the sequence must be LED → Ex470BP-40 → sample tube.

Excitation side of the optical module showing PartC with the **installed** 485 nm LED and Ex470BP-40 excitation filter.

## Installation of the Promega E4941 sample-tube holder

1. The E4941 tube must enter vertically and reach a defined mechanical stop.
2. The tube must not tilt toward either optical opening.
3. The tube wall must not touch the LED or sensor board.
4. The optical interrogation region must remain at the same height for every tube.
5. The tube must be removable without pulling the optical module or cables.
6. The holder must block stray light around the upper tube opening when the light shield is installed.

## Installation of the emission filter and single TSL2591 sensor

1. Handle the **8 x 8 x 1 mm** Em532BP-40 only by its edges.
2. Insert it into the detection-side filter pocket.
3. Confirm that it fully covers the detection opening.
4. Identify the active optical area of the TSL2591 board.
5. Orient the board so that the active area faces the emission filter directly.
6. Seat the board flat against its locating surfaces.
7. Fasten it without bowing the PCB.
8. Route the Qwiic cable away from the sample tube and optical openings.
9. Confirm once more that only one TSL2591 is present.

> **Check:** Looking from the detector side, the sequence must be sample tube → Em532BP-40 → TSL2591.

Detection side of the optical module showing the Em532BP-40 emission filter and TSL2591 sensor.

## Correct 90° optical geometry

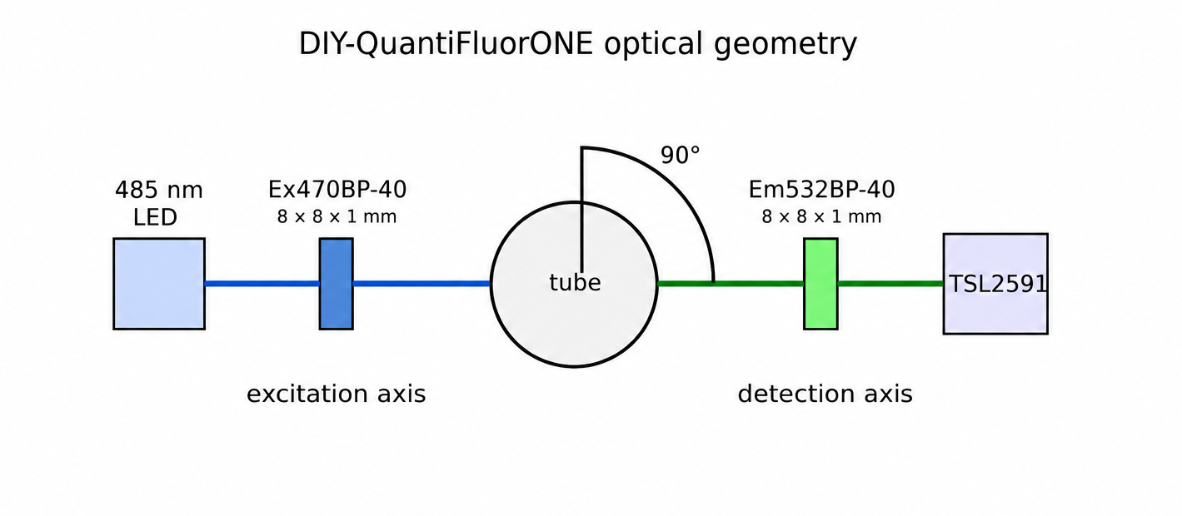
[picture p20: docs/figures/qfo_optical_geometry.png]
Optical geometry of the instrument.


The excitation axis passes from the LED through the Ex470BP-40 to the sample. The detection axis passes from the sample through the Em532BP-40 to the single TSL2591. The printed holder fixes these axes at 90°.

The workshop inspection is mechanical and visual:

- the LED aperture must point to the tube centerline;
- the detector aperture must point to the same tube region;
- the two axes must be orthogonal in the CAD and printed locating features;
- the tube must reach the designed stop;
- neither filter may be tilted, displaced, or partly outside its aperture;
- the TSL2591 active area must face the emission-filter opening.

Do not compensate for poor printed fit by angling the sensor board or LED. Correct the printed part or replace it.

## Installation of the PyBadge, multiplexer, and LED board

The excitation LED is driven by the ioRodeo `radial_16mA` fixed-current LED board, revision `ver_0p1_rev_3`. The component-placement drawing below identifies the principal components and provides a visual reference for inspection of the assembled board.

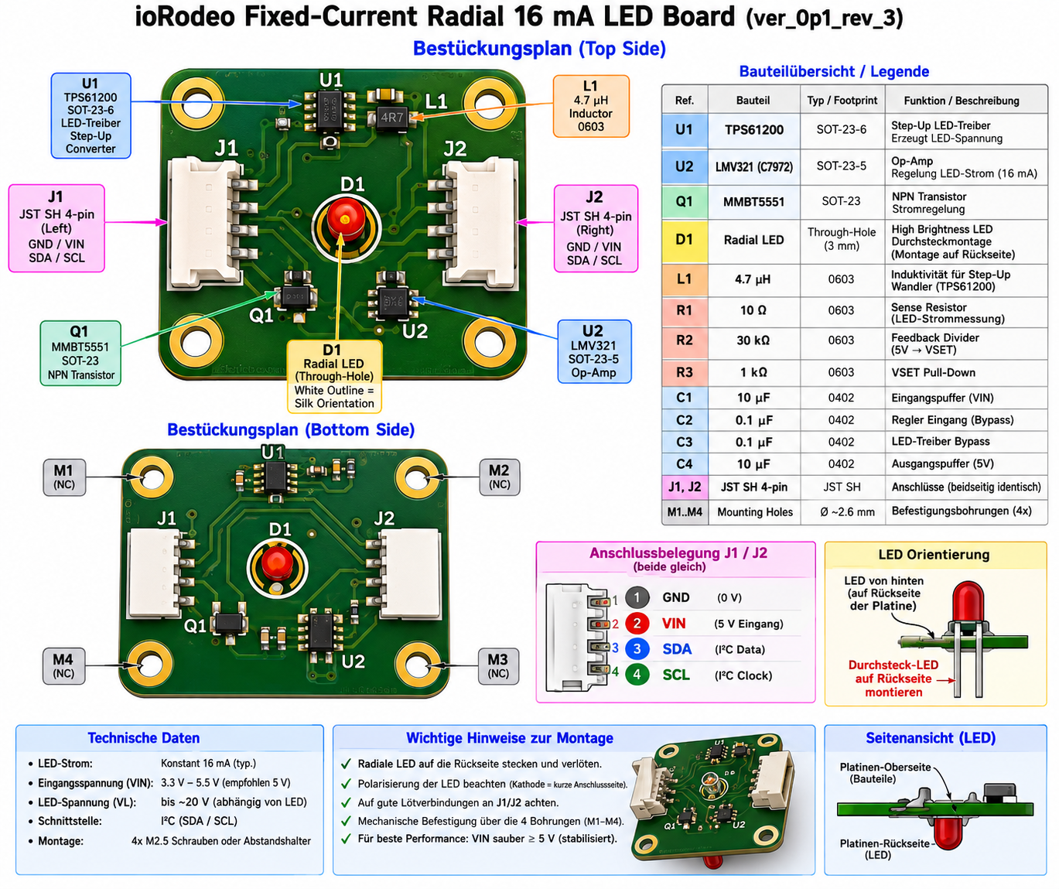
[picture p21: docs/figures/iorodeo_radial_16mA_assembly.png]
Component placement of the ioRodeo fixed-current LED board, revision . The drawing identifies the principal components used for visual inspection and assembly verification.


The principal components are:

- **U1** -- TPS61222DCKR boost converter, fixed 5 V;
- **U2** -- LMV321 operational amplifier, SOT-23-5;
- **Q1** -- MMBT5551 NPN transistor;
- **L1** -- 4.7 µH inductor;
- **C1, C2, C4** -- 10 µF ceramic capacitors;
- **C3** -- 100 nF ceramic capacitor;
- **R1** -- 10 Ω resistor;
- **R2** -- 30 kΩ resistor;
- **R3** -- 1 kΩ resistor;
- **J1, J2** -- four-pin JST-SH connectors; and
- **D1** -- radial excitation LED position.

The drawing is intended as an assembly and visual-inspection aid.

1. Place the PyBadge in the enclosure without connecting a battery.
2. Confirm access to the reset button, on/off switch, USB Micro port, and LiPo connector.
3. Fit the cover and check that no button is held down by the printed part.
4. Install the PCA9546 in its intended mounting position.
5. Install the ioRodeo `radial_16mA` board near the optical module without allowing its solder joints to touch the enclosure hardware.
6. Ensure that the LED board revision is `ver_0p1_rev_3`.
7. Keep all boards mechanically supported. Qwiic cables must not be used as structural restraints.
8. Leave enough service loop to disconnect a board without pulling directly on the wire bundle.

Interior view of the assembled instrument showing the PyBadge, PCA9546 I²C multiplexer, modified ioRodeo LED board, TSL2591 sensor and internal wiring.

## STEMMA QT / Qwiic wiring and I²C addresses

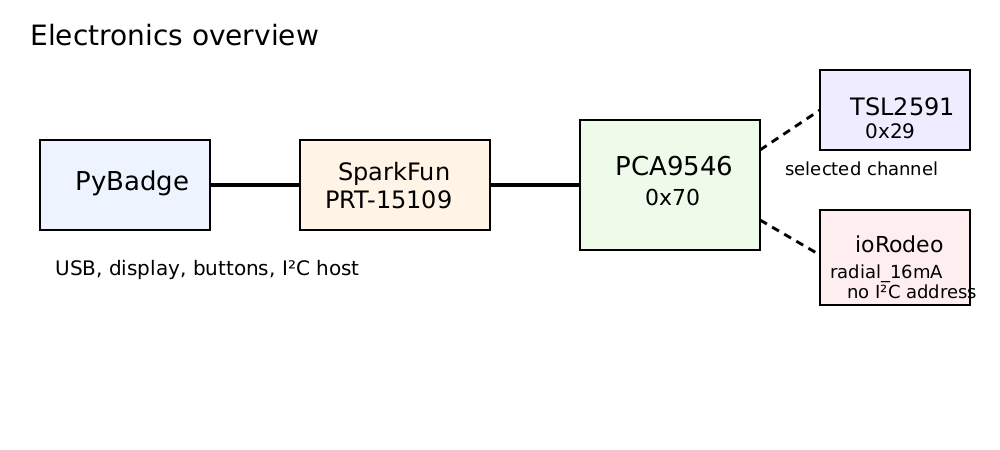
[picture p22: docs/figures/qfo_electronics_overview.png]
Electronics overview. The TSL2591 may be connected to any available downstream PCA9546 channel. The firmware scans the downstream channels for the sensor at address ; therefore, a fixed downstream channel assignment is not required.


The confirmed address map is:

| Device | Address | Expected in I²C scan? |
|---|---:|---|
| PCA9546 multiplexer | `0x70` | yes, on the upstream bus |
| TSL2591 | `0x29` | yes, on its selected downstream channel |
| ioRodeo fixed 16 mA LED board | none | no |

The intended upstream connection is:

`PyBadge I²C connector → SparkFun PRT-15109 → PCA9546 upstream connector`

The exact downstream PCA9546 channel assignment, cable order, and cable lengths remain to be transcribed from the final instrument. They are deliberately marked `TBD` in the cable map rather than guessed.

When inserting JST-SH connectors:

- hold the plug, not the cable;
- check alignment before applying pressure;
- do not lever the socket from the PCB;
- do not connect or disconnect while the instrument is powered;
- verify that no cable crosses the tube opening or blocks a filter aperture.

## Cable routing, strain relief, and prevention of light leakage

1. Route cables along enclosure walls and printed channels.
2. Keep the optical chamber clear of wire loops.
3. Provide a service loop near each detachable board.
4. Add strain relief close to the PyBadge adapter and optical module, not directly at the JST-SH socket.
5. Avoid sharp folds in Qwiic cables.
6. Keep cables clear of the reset button, power switch, and USB connector.
7. Close unused optical and cable openings with the intended printed cover or opaque material.
8. Inspect the closed enclosure in a dark room while illuminating its exterior from several directions.
9. Pay particular attention to the tube opening, filter pockets, cable pass-throughs, display edge, and the joint between the optical module and base.

The final light shield must be fitted before blank stability and low-signal performance are evaluated.

## Recommended step-by-step assembly sequence

1. Print and inspect all mechanical parts.
2. Test the E4941 tube fit using an empty tube.
3. Test filter-pocket fit using a **8 x 8 x 1 mm** test piece without touching the optical apertures.
4. Install the 485 nm LED on the ioRodeo revision-3 board.
5. Install the Ex470BP-40 excitation filter.
6. Install the E4941 sample-tube holder.
7. Install the Em532BP-40 emission filter.
8. Install the single TSL2591 with its active area facing the filter.
9. Mount the optical module on the instrument base.
10. Mount the PyBadge in its enclosure.
11. Mount the PCA9546 and LED board.
12. Connect the upstream adapter and downstream Qwiic cables according to the final cable map.
13. Route cables and add strain relief.
14. Fit the light shield.
15. Perform the pre-power inspection.
16. Carry out first power-up using USB before adding an optional LiPo battery.
17. Record the actual channel map, cable lengths, and any assembly deviations.

## Complete Measurement Setup

Complete measurement setup including the DIY-QuantiFluorONE-dsDNA-Fluorometer, Promega QuantiFluor® ONE dsDNA System, pipettes, PCR tubes and the supporting laboratory equipment used for routine measurements.

## Pre-power inspection

Do not power the instrument until every item below is checked.

- [ ] PyBadge is switched off.
- [ ] USB is disconnected.
- [ ] LiPo battery is disconnected or confirmed undamaged and correctly connected.
- [ ] LED polarity is correct.
- [ ] No LED lead or solder joint contacts the enclosure hardware.
- [ ] Ex470BP-40 is installed on the LED side.
- [ ] Em532BP-40 is installed on the sensor side.
- [ ] TSL2591 active area faces the emission filter.
- [ ] Only one TSL2591 is installed.
- [ ] PCA9546 orientation and upstream connection are correct.
- [ ] All JST-SH plugs are fully seated and correctly aligned.
- [ ] No cable is pinched by the cover.
- [ ] Reset and power controls move freely.
- [ ] USB Micro connector is accessible without forcing the cable.
- [ ] Tube can be inserted and removed without contacting electronics.
- [ ] Light shield and enclosure close without pressure on the boards.
- [ ] No loose screw, wire clipping, or printed debris remains inside.

## First power-up and hardware checks

Use USB power for the first check. Leave the optional LiPo disconnected.

1. Connect a known-good USB Micro data cable.
2. Switch on the PyBadge.
3. Confirm that the display starts normally.
4. Confirm that the PCA9546 is detected at `0x70`.
5. Select the configured downstream channel and confirm that the TSL2591 is detected at `0x29`.
6. Do not expect an I²C address for the fixed-current LED board.
7. Confirm that the 485 nm LED illuminates when the hardware and firmware configuration calls for it.
8. Do not look directly into the LED or the excitation aperture.
9. Place an empty E4941 tube in the holder and close the light shield.
10. Compare the sensor reading with the shield open and closed. A large room-light response indicates incomplete shielding or an uncovered optical path.
11. Insert the intended blank and check that repeated readings are stable enough for subsequent calibration work.
12. Record any channel or cable-map corrections immediately.

Firmware installation, menu operation, and analytical calibration are covered in their own chapters.

## Troubleshooting

| Symptom | Likely cause | Workshop check |
|---|---|---|
| PyBadge does not start | power switch off, charge-only/failed cable, low battery, short circuit | disconnect external modules; test USB cable and switch position |
| PCA9546 not found at `0x70` | adapter orientation, loose connector, damaged cable, upstream wiring error | inspect PyBadge-to-PRT-15109-to-PCA9546 chain |
| TSL2591 not found at `0x29` | wrong channel, loose downstream cable, incorrect orientation, damaged socket | select each documented channel; inspect cable and sensor board |
| LED board not shown in scan | normal behavior | the fixed 16 mA board has no I²C address |
| LED remains dark | reversed LED, poor solder joint, no supply, damaged LED or driver board | power off; verify polarity and continuity before replacement |
| Sensor saturates | light shield open, emission filter missing, filter displaced, direct LED path | close shield and inspect filter sequence and geometry |
| Signal is unexpectedly low | LED/filter misalignment, sensor faces away, dirty filter, tube not seated | inspect optical axis, active area, tube stop, and optical surfaces |
| Blank changes with room lighting | light leak at tube opening, cable slot, enclosure seam, or display edge | dark-room flashlight inspection; refit shield and covers |
| Tube jams | support residue, undersized bore, damaged tube | remove tube; clean or reprint holder; do not force it |
| Readings change after handling | loose filter, sensor board movement, cable strain | inspect retention and strain relief; repeat mechanical check |

## Cleaning, maintenance, and replacement of optical components

- Switch off and disconnect USB and LiPo before opening the instrument.
- Remove the sample tube immediately after use.
- Wipe spilled reagent before it reaches filter pockets or PCB surfaces.
- Handle filters by the edges using clean gloves or suitable tweezers.
- Use clean optical tissue or a blower intended for optical work.
- Do not use abrasive paper, cotton fibers, or aggressive solvent on filter coatings.
- Check compatibility before applying alcohol or another solvent to printed parts.
- Do not scrape the active TSL2591 area.
- Replace cracked, delaminated, deeply scratched, or chemically attacked filters.
- Recheck blank response and recalibrate after replacing the LED, either optical filter, the sample holder, or the TSL2591.
- Inspect Qwiic sockets and cables periodically for looseness or strain damage.
- Inspect the LiPo for swelling, puncture, unusual heat, or damaged leads. Remove a suspect battery from service.

## Safety notes

- Do not stare directly into the 485 nm LED, especially when the excitation filter or light shield is removed.
- Disconnect power before soldering, rewiring, installing filters, or moving boards.
- Prevent metal tools and loose screws from shorting the PyBadge or LED board.
- Observe LiPo polarity. Do not use swollen, damaged, wet, or overheated batteries.
- Charge the battery only through the intended PyBadge charging circuit and a suitable USB supply.
- Keep liquids away from the open electronics.
- Follow the safety data sheets and laboratory rules for QuantiFluor ONE reagent, DNA standards, cleaning agents, and samples.
- Dispose of reagents, samples, tubes, electronics, and batteries according to local rules.

## Reproducibility files and references

This package includes:

- PyBadge enclosure STEP files;
- CAD screenshots of the enclosure and optical module;
- ioRodeo `radial_16mA` revision-3 KiCad, Gerber, BOM, CPL;
- Adafruit PyBadge EagleCAD schematic and board files;
- upstream license files and source notes;
- the current assembled-instrument photograph;
- BOM, wiring, I²C, figure, and open-item manifests;
- STEP-Files.

The third-party source locations and licenses are recorded in `THIRD_PARTY_NOTICES.md` and the `SOURCE.md` files beside the upstream hardware data.

---

⬅️ Previous Chapter: [Theory and References](03_theory_and_references.md)

📖 [Documentation Summary](SUMMARY.md)

➡️ Next Chapter: [Software Installation](05_software_installation.md)

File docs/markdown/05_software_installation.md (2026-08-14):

---
document-status: "Current"
validation-status: "Validated configuration"
date: "2026-08-14"
---

> **Current supported software set:** PyBadge UF2 bootloader 3.15.0, Adafruit CircuitPython 9.1.1, and the unchanged `QuantiFluorONE_Firmware_1.0.0-rc2-stable.zip` release.
>
> **Repository policy:** one instrument, one supported QuantiFluorONE firmware release, and one documented installation procedure.

## Purpose and scope

This chapter describes the workshop procedure for preparing an Adafruit PyBadge and installing the current QuantiFluorONE firmware. It covers:

- backing up an existing `CIRCUITPY` drive;
- distinguishing normal restart, CircuitPython safe mode, and UF2 bootloader mode;
- checking or updating the PyBadge bootloader;
- installing CircuitPython 9.1.1;
- performing a clean installation of the complete stable RC2 release;
- carrying out the first startup and basic file-system checks.

The physical reset button is mounted on the **underside of the PyBadge**. It is reached from below through the dedicated reset access opening in the enclosure.

## Software files in the repository

All installation components are stored under one top-level directory:

```text
software/
├── README.md
├── bootloader/
│   └── 3.15.0/
│       ├── update-bootloader-arcade_pybadge-v3.15.0.uf2
│       ├── bootloader-arcade_pybadge-v3.15.0.bin
│       └── README.md
├── circuitpython/
│   └── 9.1.1/
│       ├── adafruit-circuitpython-pybadge-en_US-9.1.1.uf2
│       └── README.md
└── quantifluorone_firmware/
    ├── QuantiFluorONE_Firmware_1.0.0-rc2-stable.zip
    ├── README.md
    └── SHA256SUMS.txt
```

**Component:** PyBadge bootloader updater  
**Repository file:**  
`software/bootloader/3.15.0/`  
`update-bootloader-arcade_pybadge-v3.15.0.uf2`  
**When required:** Only when the bootloader must be updated

---

**Component:** Raw bootloader image  
**Repository file:**  
`software/bootloader/3.15.0/`  
`bootloader-arcade_pybadge-v3.15.0.bin`  
**When required:** Archive and technical recovery only

---

**Component:** CircuitPython  
**Repository file:**  
`software/circuitpython/9.1.1/`  
`adafruit-circuitpython-pybadge-en_US-9.1.1.uf2`  
**When required:** After a bootloader update or for a clean CircuitPython installation

---

**Component:** Current device firmware  
**Repository file:**  
`software/quantifluorone_firmware/`  
`QuantiFluorONE_Firmware_1.0.0-rc2-stable.zip`  
**When required:** Clean QuantiFluorONE installation

Use a computer with a USB port and a known-good USB Micro **data cable**. A charge-only cable cannot expose the PyBadge drives.

Use a short **non-conductive** tool to reach the reset switch through the underside opening. The eraser end of a pencil or a suitable plastic rod is preferable to a metal tool.

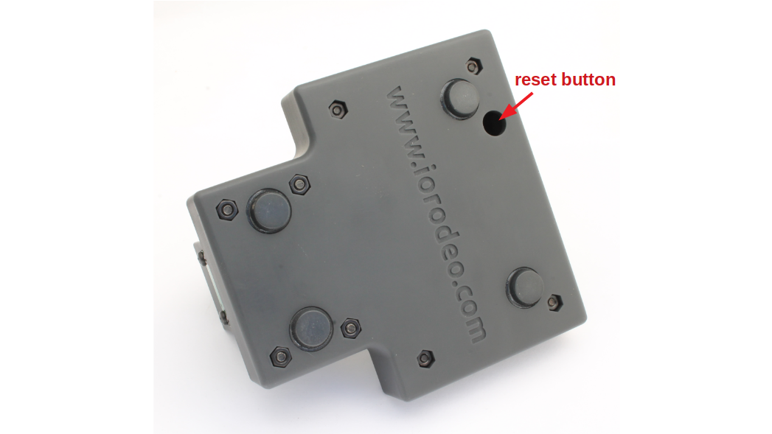
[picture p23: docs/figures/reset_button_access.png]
The reset switch is mounted on the underside of the PyBadge and is reached from below through the enclosure opening.


## One supported QuantiFluorONE firmware

The current supported device firmware is the unchanged archive:

```text
software/quantifluorone_firmware/
QuantiFluorONE_Firmware_1.0.0-rc2-stable.zip
```

Do not shorten, clean, rename, rebuild, or replace this archive with a reduced derivative. The ZIP file is the preserved software state that was tested on the instrument.

Earlier development versions remain traceable through Git history, tags, or GitHub releases, but they are not presented in the main repository as competing installation choices.

> > **Important:** "stable RC2" describes the tested firmware package and operating workflow. The documented multipoint calibration and analytical workflow have been evaluated using the validation procedure described in Chapter 10.

## Back up the current device

> **Back up the complete `CIRCUITPY` drive before continuing.** Deleting its contents also removes measurement logs, calibration files, configuration files, saved blank and state files, and other user-generated data stored on the device.

1. Connect the instrument using a USB data cable.
2. Switch the PyBadge on.
3. Open the `CIRCUITPY` drive if it appears.
4. Copy its complete contents to a dated backup folder on the computer.
5. Confirm that the backup includes all CSV and JSON files that must be retained.
6. Safely eject `CIRCUITPY` before resetting, disconnecting, or power-cycling the instrument.

Do not copy old configuration, state, calibration, or log files back to the device automatically after installation. Restore only files that are known to be compatible with the current firmware.

## Reset timing: three different results

| Reset action | Result | Drive | Main use |
|---|---|---|---|
| One press | normal restart | `CIRCUITPY` | restart the application or leave safe mode |
| **Slow double-click** | CircuitPython safe mode | `CIRCUITPY` | copy, replace, download, or delete firmware, CSV, and JSON files |
| Fast double-click | UF2 bootloader mode | `PYBADGEBOOT` or `BADGEBOOT` | install a bootloader-updater or CircuitPython UF2 file |

### Slow double-click: required for file maintenance

Use the **slow double-click** before modifying files on `CIRCUITPY`:

1. Press the underside reset button once through the access opening.
2. Allow the startup sequence to begin.
3. Press Reset again during the approximately one-second safe-mode window.

Safe mode prevents the QuantiFluorONE application from running while files are changed. Automatic reload is disabled, making this the preferred state for copying firmware, replacing JSON files, downloading CSV logs, and deleting old files.

### Fast double-click: UF2 bootloader mode

Press the underside reset button twice in quick succession. The PyBadge display changes to the UF2 bootloader screen, and the computer mounts `PYBADGEBOOT` or `BADGEBOOT`.

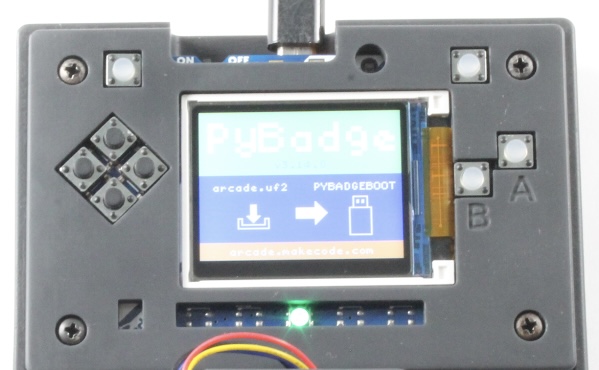
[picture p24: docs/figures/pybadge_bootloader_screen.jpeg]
PyBadge UF2 bootloader screen.


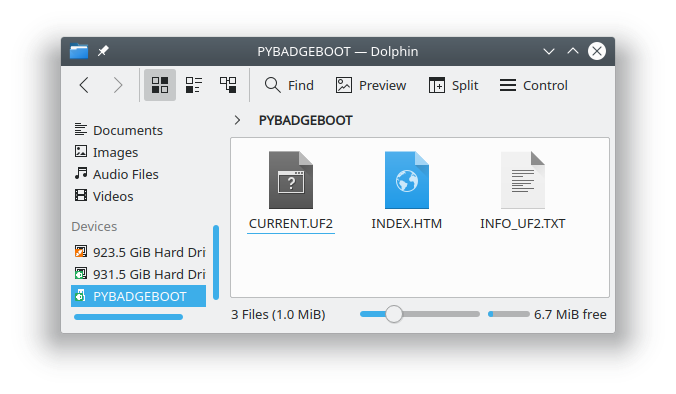
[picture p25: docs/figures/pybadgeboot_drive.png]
Typical contents of the PyBadge UF2 boot drive.


If `PYBADGEBOOT` appears when `CIRCUITPY` was intended, press Reset once to restart normally and repeat with slower timing.

## Check or update the UF2 bootloader

A bootloader update is not required for every firmware installation.

1. Enter UF2 bootloader mode with a fast double-click.
2. Open `INFO_UF2.TXT` on `PYBADGEBOOT` or `BADGEBOOT`.
3. Read the installed bootloader version.

To install the supplied version 3.15.0 updater:

1. Copy `update-bootloader-arcade_pybadge-v3.15.0.uf2` to the UF2 boot drive.
2. Wait while the updater runs and the boot drive reappears.
3. Open `INFO_UF2.TXT` again and verify version 3.15.0.
4. Install CircuitPython 9.1.1 as described in the next section.

> **Do not copy** `bootloader-arcade_pybadge-v3.15.0.bin` to `PYBADGEBOOT` or `BADGEBOOT`. The BIN file is retained only for archival and technical recovery purposes.

## Install CircuitPython 9.1.1

1. Confirm that the current `CIRCUITPY` contents have been backed up.
2. Enter UF2 bootloader mode with a **fast double-click**.
3. Copy `adafruit-circuitpython-pybadge-en_US-9.1.1.uf2` to `PYBADGEBOOT` or `BADGEBOOT`.
4. Wait for the board to restart automatically.
5. Confirm that the UF2 boot drive disappears and a new drive named `CIRCUITPY` appears.
6. Safely eject `CIRCUITPY` before disconnecting or restarting the instrument.

The stable RC2 archive records the tested runtime in `boot_out.txt` as:

```text
Adafruit CircuitPython 9.1.1 on 2024-07-22
Adafruit Pybadge with samd51j19
Board ID: pybadge
```

## Clean installation of QuantiFluorONE stable RC2

This is the current recommended workshop procedure.

### Prepare the firmware folder

1. Locate:

   ```text
   software/quantifluorone_firmware/
   QuantiFluorONE_Firmware_1.0.0-rc2-stable.zip
   ```

2. Extract the ZIP file to a normal folder on the computer.
3. Open the extracted outer folder named:

   ```text
   QuantiFluorONE_Firmware_1.0.0-rc2-stable
   ```

4. Leave the original ZIP file unchanged in the repository.

### Empty `CIRCUITPY`

1. Confirm once more that the complete previous drive has been backed up.
2. Enter safe mode with the **slow double-click**.
3. Open the root of `CIRCUITPY`.
4. Select all existing files and folders on `CIRCUITPY`.
5. Delete the selected contents.
6. Confirm that no old firmware, library, configuration, state, calibration, or log files remain.

### Copy the complete stable release

1. In the extracted stable-release folder, select **all files and folders inside** `QuantiFluorONE_Firmware_1.0.0-rc2-stable`.
2. Copy the complete selected contents to the **root of the empty `CIRCUITPY` drive**.
3. Do **not** copy the enclosing `QuantiFluorONE_Firmware_1.0.0-rc2-stable` folder itself. Files such as `boot.py` and `code.py` must be located directly in the root of `CIRCUITPY`.
4. Wait until copying is completely finished.
5. Compare the top-level files and folders with the extracted release folder.
6. Safely eject `CIRCUITPY`.
7. Press Reset once or power-cycle the device for a normal restart.

This full-copy procedure installs one complete, internally consistent release and avoids mixing files from different firmware generations.

## First startup and hardware check

After the normal restart:

1. Confirm that the splash screen appears.
2. Confirm the display banner:

   ```text
   QuantiFluorONE v1.0 RC2
   ```

3. Confirm that no startup error screen is shown.
4. Open the SELECT menu.
5. Choose `LOAD MP CAL` only when the supplied or a compatible `quantifluorone_multipoint.json` is present.
6. Measure a fresh reagent blank with START.
7. Measure a test sample with A.

The display may show `cal=none c=uncalibrated` until a calibration is loaded or created. After loading a compatible calibration, verify that the calibration information displayed by the instrument corresponds to the calibration intended for the current measurement series.

## CSV and JSON write behaviour

The included `boot.py` provides two different file-system modes:

- with a USB data host connected, `CIRCUITPY` remains writable by the computer and read-only to the firmware;
- with a charger, power bank, or approved LiPo supply, the firmware can save blank state, calibration state, and CSV rows.

For firmware-generated writes:

1. safely eject and disconnect the USB data host;
2. power the PyBadge from a USB charger, power bank, or the approved LiPo supply;
3. restart the instrument normally;
4. perform the measurement or save operation.

Use the **slow double-click** whenever returning to computer-based file maintenance.

## Updating or reinstalling the same supported release

Use the same clean procedure whenever a complete reinstall is needed:

1. back up `CIRCUITPY`;
2. enter safe mode with the slow double-click;
3. delete the complete contents of `CIRCUITPY`;
4. extract the unchanged stable RC2 archive;
5. copy all contents inside the extracted release folder to the root of `CIRCUITPY`;
6. safely eject and restart;
7. verify the RC2 display banner.

Do not merge a new installation with residual files from an older device state.

## Troubleshooting

| Symptom | Likely cause or corrective action |
|---|---|
| No USB drive appears | check the power switch, USB port, and use a known data-capable cable |
| `PYBADGEBOOT` appears instead of `CIRCUITPY` | reset presses were too fast; press once to restart, then use the slow double-click if file maintenance is required |
| `CIRCUITPY` appears but files cannot be changed reliably | enter safe mode with the slow double-click before copying or deleting files |
| Device remains in safe mode | safely eject, then press Reset once or power-cycle |
| PyBadge repeatedly reloads while files are copied | use safe mode so that the application is not running during file maintenance |
| Firmware starts with missing-module or missing-file errors | repeat the clean installation and confirm that the complete release contents were copied to the root of `CIRCUITPY` |
| `boot.py` or `code.py` is not visible in the root of `CIRCUITPY` | the enclosing release folder was copied instead of its contents; empty the drive and repeat the installation |
| Firmware starts but does not log CSV while connected to a computer | expected project file-system behaviour; use a charger, power bank, or LiPo supply for firmware-side writes |
| Old measurement or calibration state reappears | residual files were retained or restored; repeat the clean installation and restore only confirmed compatible files |

The following screen indicates CircuitPython automatic reload or a soft reboot, not UF2 bootloader mode:

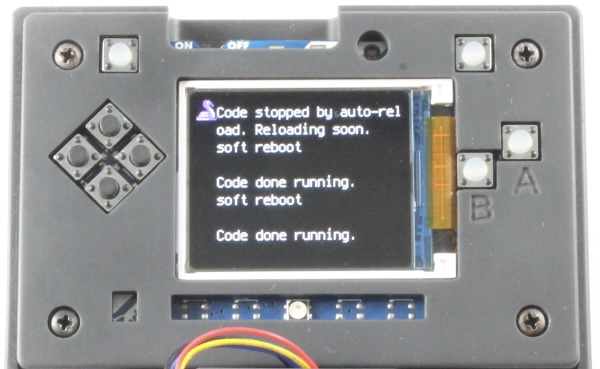
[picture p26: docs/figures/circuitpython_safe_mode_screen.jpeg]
CircuitPython soft-reboot and automatic-reload screen.


## References

- IO Rodeo. *Installing/upgrading CircuitPython and the bootloader.* https://blog.iorodeo.com/installing-upgrading-circuitpython-or-the-bootloader/
- IO Rodeo. *Installing/upgrading the firmware.* https://blog.iorodeo.com/installing-upgrading-the-firmware/
- Adafruit. *Installing CircuitPython — Adafruit PyBadge and PyBadge LC.* https://learn.adafruit.com/adafruit-pybadge/installing-circuitpython
- Adafruit. *Update the PyBadge Bootloader.* https://learn.adafruit.com/adafruit-pybadge/updating-the-bootloader
- Adafruit. *Troubleshooting — Safe Mode.* https://learn.adafruit.com/adafruit-pybadge/troubleshooting
- CircuitPython.org. *PyBadge downloads.* https://circuitpython.org/board/pybadge/

This chapter adapts the general IO Rodeo and Adafruit procedures to the current QuantiFluorONE hardware, enclosure, software versions, and the tested clean-installation workflow used for this instrument.

---

⬅️ Previous Chapter: [Hardware and Assembly](04_hardware_and_assembly.md)

📖 [Documentation Summary](SUMMARY.md)

➡️ Next Chapter: [Getting Started – Basic Operation and Menu Navigation](06_getting_started_basic_operation_and_menu_navigation.md)

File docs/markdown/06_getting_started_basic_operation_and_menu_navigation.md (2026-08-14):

---
document-status: "Current"
validation-status: "Validated configuration"
date: "2026-08-14"
---

> **Firmware basis:** QuantiFluorONE `QF1-1.0.0-rc2`, display version `v1.0 RC2`.

## Front-panel controls

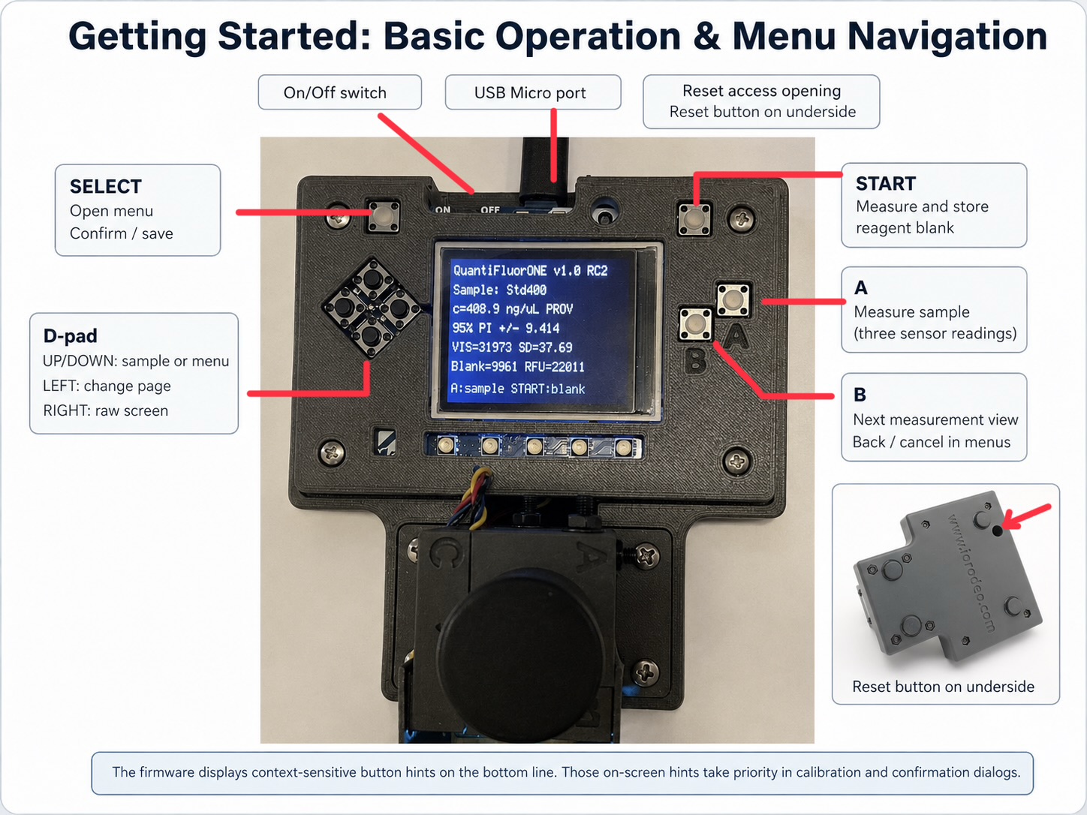
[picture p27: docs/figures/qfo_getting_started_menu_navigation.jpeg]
QuantiFluorONE front-panel controls for firmware QF1-1.0.0-rc2.


The firmware defines the controls as follows:

| Physical control | Firmware name | Main measurement-screen function | Menu or dialog function |
|---|---|---|---|
| Upper-left button | `SELECT` | Open the SELECT menu | Open, confirm, load, or save the highlighted action |
| Upper-right button | `START` | Measure and store the reagent blank | Measure a calibration blank or the next blank in the ten-blank study |
| A button | `A` | Measure the selected sample; one cycle contains three sensor readings | Measure the selected high standard during two-point calibration |
| B button | `B` | Cycle Live → Details → RAW → Live | Back or cancel |
| D-pad UP/DOWN | `UP/DOWN` | Select the sample ID | Select a menu item or standard concentration |
| D-pad RIGHT | `RIGHT` | Open or leave the RAW screen | Not used for menu selection |
| D-pad LEFT | `LEFT` | Change RAW page | Change calibration-result or calibration-status page |
| On/Off switch | power | Turn the instrument on or off | — |
| Reset access opening | reset | Restart the PyBadge | Used for normal reset, slow-double-click safe mode, or fast-double-click UF2 bootloader mode |
| USB Micro port | USB | Power, charging, programming, and file access | — |

The last line of the display shows context-sensitive button hints. These hints take priority whenever a calibration or confirmation dialog is open.

## Preparing and documenting the sample list

Before starting a measurement series, the sample identifiers can be entered in `quantifluorone_config.json`. This is recommended because the selected sample ID is written to the measurement CSV file and allows each measurement to be assigned directly to the corresponding laboratory sample.

Editing the sample list is optional. If the list is not updated, the exact order in which the physical samples are measured must be recorded separately in the laboratory notebook. Without such a record, measurements in the CSV file may no longer be assignable reliably to the original samples after the measurement series.

### Editing the sample list

1. Connect the switched-on fluorometer to the computer using a USB data cable.

2. Enter CircuitPython safe mode using the **slow double-click** of the Reset button:
   - press Reset once;
   - allow the restart sequence to begin; and
   - press Reset a second time during the approximately one-second startup window.

3. Confirm that the `CIRCUITPY` drive is available on the computer.

4. Open `quantifluorone_config.json` with a plain-text editor.

   Suitable examples are:
   - Windows Notepad;
   - Notepad++;
   - Visual Studio Code; or
   - another editor that saves plain-text files without changing the JSON structure.

   Do not edit the file with a word processor such as Microsoft Word.

5. Locate the `samples` section and enter the required sample identifiers, for example:

```json
"samples": {
  "list": ["Blank", "Std400", "QC1", "Sample01", "Sample02"],
  "selected_index": 0
}
```

Use short, unique identifiers because the display width is limited. The complete identifier is retained in the measurement data even when only part of it is visible on the instrument display.

6. Save `quantifluorone_config.json` without changing its filename or file type.

7. Safely eject the `CIRCUITPY` drive from the computer.

8. Disconnect the USB data connection.

9. Connect the fluorometer to its normal standalone power source, such as a power bank, and restart it normally.

10. Use **UP/DOWN** on the measurement screen to select the required sample ID before measuring the corresponding sample with **A**.

### If the sample list is not edited

Updating `quantifluorone_config.json` is not mandatory. The instrument can also be used with the existing sample list.

In this case, record the physical samples and their measurement order explicitly in the laboratory notebook, for example:

```text
Measurement 1  = Sample A17
Measurement 2  = Sample A18
Measurement 3  = Sample B03
Measurement 4  = Sample B04
```

**Important:** The CSV file records the sample identifier selected on the instrument. If this identifier does not correspond to the actual sample and no separate measurement-order record is kept, the analytical result may not be assignable reliably to the original sample afterwards.

Whenever practical, prepare the sample list before the measurement series and keep the displayed sample order consistent with the physical order of the prepared tubes.

## Normal measurement workflow

1. Switch the instrument on and wait for `QuantiFluorONE v1.0 RC2`.
2. Use D-pad UP or DOWN to select the required sample ID.
3. Insert a fresh reagent blank and close the light shield.
4. Press START. The instrument performs three TSL2591 readings and stores the blank mean and standard deviation.
5. Replace the blank with the prepared sample and close the light shield.
6. Press A. The instrument performs one sample cycle of three sensor readings.
7. Read concentration, prediction interval, VIS, standard deviation, blank, and RFU from the live screen.
8. Press B for the details screen or RIGHT for raw readings.

## SELECT menu

Press SELECT from the live screen to open:

```text
SELECT MENU
>2-PT CAL
 10-BLANK L/Q
 LOAD MP CAL
 CAL STATUS
 CLEAR CAL
```

Use UP/DOWN to move the selection, SELECT to open or confirm, and B to return or cancel.

## Display views

### Live

The live screen displays the sample ID, concentration or calibration status, prediction interval or LOD/LOQ, VIS mean and SD, blank, and RFU.

### Details

Press B from Live. The details screen shows FULL, IR, VIS, RFU, concentration, sensor channel, gain, and integration time.

### RAW

Press B again, or press RIGHT from Live/Details. LEFT changes between the two raw-data pages. RIGHT returns to Live.

## Multipoint calibration import

1. Place the compatible `quantifluorone_multipoint.json` file in the root of `CIRCUITPY`.
2. Disconnect the USB data host and power the device from a charger or power bank so the firmware can write its state files.
3. Press SELECT.
4. Choose `LOAD MP CAL`.
5. Confirm with SELECT.
6. Measure a fresh reagent blank with START before measuring samples.

The multipoint calibration used for quantitative measurements must correspond to the validated calibration workflow described in this repository. Verify the calibration identity, working range, concentration basis, and status before measuring samples.

## Managing CSV and JSON files: use the slow double-click

> **Important — slow double-click required:** Before copying, replacing, deleting, or downloading CSV, JSON, or firmware files, enter CircuitPython **safe mode** with a slow double-click of the Reset button. Press Reset once, then press it again during the approximately one-second startup window. The display reports that code has stopped and will not run the saved application.

In safe mode:

- `CIRCUITPY` remains available to the computer;
- the QuantiFluorONE application does not run;
- automatic reload is disabled;
- files can be copied, downloaded, replaced, or deleted without the firmware actively using them.

A **fast** double-click is different: it opens `PYBADGEBOOT` or `BADGEBOOT` and is used only for UF2 installation.

## Files produced or used by RC2

| File | Purpose |
|---|---|
| `quantifluorone_log_v100rc2.csv` | Measurement log |
| `quantifluorone_state.json` | Blank and interface state |
| `quantifluorone_calibration.json` | Active saved calibration |
| `quantifluorone_multipoint.json` | Multipoint model imported through `LOAD MP CAL` |
| `quantifluorone_config.json` | Hardware, measurement, sample, assay, and calibration settings |

Always back up required data and safely eject the drive before resetting, switching off, or disconnecting USB.

---

⬅️ Previous Chapter: [Software Installation](05_software_installation.md)

📖 [Documentation Summary](SUMMARY.md)

➡️ Next Chapter: [Calibration Suite and Data Transfer](07_calibration_suite_and_data_transfer.md)

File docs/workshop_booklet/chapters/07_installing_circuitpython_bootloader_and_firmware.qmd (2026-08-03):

---
title: "QuantiFluorONE – PyBadge Firmware Installation"
number-sections: true
toc: true
fig-cap-location: bottom
---

> **Current supported software set:** PyBadge UF2 bootloader 3.15.0, Adafruit CircuitPython 9.1.1, and the unchanged `QuantiFluorONE_Firmware_1.0.0-rc2-stable.zip` release.
>
> **Repository policy:** one instrument, one supported QuantiFluorONE firmware release, and one documented installation procedure.

## 1. Purpose and scope

This chapter describes the workshop procedure for preparing an Adafruit PyBadge and installing the current QuantiFluorONE firmware. It covers:

- backing up an existing `CIRCUITPY` drive;
- distinguishing normal restart, CircuitPython safe mode, and UF2 bootloader mode;
- checking or updating the PyBadge bootloader;
- installing CircuitPython 9.1.1;
- performing a clean installation of the complete stable RC2 release;
- carrying out the first startup and basic file-system checks.

The physical reset button is mounted on the **underside of the PyBadge**. It is reached from below through the dedicated reset access opening in the enclosure.

## 2. Software files in the repository

All installation components are stored under one top-level directory:

```text
software/
├── README.md
├── bootloader/
│   └── 3.15.0/
│       ├── update-bootloader-arcade_pybadge-v3.15.0.uf2
│       ├── bootloader-arcade_pybadge-v3.15.0.bin
│       └── README.md
├── circuitpython/
│   └── 9.1.1/
│       ├── adafruit-circuitpython-pybadge-en_US-9.1.1.uf2
│       └── README.md
└── quantifluorone_firmware/
    ├── QuantiFluorONE_Firmware_1.0.0-rc2-stable.zip
    ├── README.md
    └── SHA256SUMS.txt
```

The former top-level `firmware/` directory is obsolete and must not be retained after this restructuring.

| Component | Repository file | When required |
|---|---|---|
| PyBadge bootloader updater | `software/bootloader/3.15.0/update-bootloader-arcade_pybadge-v3.15.0.uf2` | only when the bootloader must be updated |
| Raw bootloader image | `software/bootloader/3.15.0/bootloader-arcade_pybadge-v3.15.0.bin` | archive and technical recovery only |
| CircuitPython | `software/circuitpython/9.1.1/adafruit-circuitpython-pybadge-en_US-9.1.1.uf2` | after a bootloader update or for a clean CircuitPython installation |
| Current device firmware | `software/quantifluorone_firmware/QuantiFluorONE_Firmware_1.0.0-rc2-stable.zip` | clean QuantiFluorONE installation |

Use a computer with a USB port and a known-good USB Micro **data cable**. A charge-only cable cannot expose the PyBadge drives.

Use a short **non-conductive** tool to reach the reset switch through the underside opening. The eraser end of a pencil or a suitable plastic rod is preferable to a metal tool.

The reset switch is mounted on the underside of the PyBadge and is reached from below through the enclosure opening.

## 3. One supported QuantiFluorONE firmware

The current supported device firmware is the unchanged archive:

```text
software/quantifluorone_firmware/
QuantiFluorONE_Firmware_1.0.0-rc2-stable.zip
```

Do not shorten, clean, rename, rebuild, or replace this archive with a reduced derivative. The ZIP file is the preserved software state that was tested on the instrument.

Earlier development versions remain traceable through Git history, tags, or GitHub releases, but they are not presented in the main repository as competing installation choices.

> **Important:** “stable RC2” describes the tested firmware package and operating workflow. The included multipoint calibration remains marked `PROVISIONAL` and is not a completed analytical-method validation.

The original archive also contains documentation that describes an earlier selective overlay procedure. Those files remain unchanged as part of the release record. For the current workshop build, follow the clean full-copy procedure in this chapter.

## 4. Back up the current device

> **Back up the complete `CIRCUITPY` drive before continuing.** Deleting its contents also removes measurement logs, calibration files, configuration files, saved blank and state files, and other user-generated data stored on the device.

1. Connect the instrument using a USB data cable.
2. Switch the PyBadge on.
3. Open the `CIRCUITPY` drive if it appears.
4. Copy its complete contents to a dated backup folder on the computer.
5. Confirm that the backup includes all CSV and JSON files that must be retained.
6. Safely eject `CIRCUITPY` before resetting, disconnecting, or power-cycling the instrument.

Do not copy old configuration, state, calibration, or log files back to the device automatically after installation. Restore only files that are known to be compatible with the current firmware.

## 5. Reset timing: three different results

| Reset action | Result | Drive | Main use |
|---|---|---|---|
| One press | normal restart | `CIRCUITPY` | restart the application or leave safe mode |
| **Slow double-click** | CircuitPython safe mode | `CIRCUITPY` | copy, replace, download, or delete firmware, CSV, and JSON files |
| Fast double-click | UF2 bootloader mode | `PYBADGEBOOT` or `BADGEBOOT` | install a bootloader-updater or CircuitPython UF2 file |

### 5.1 Slow double-click: required for file maintenance

Use the **slow double-click** before modifying files on `CIRCUITPY`:

1. Press the underside reset button once through the access opening.
2. Allow the startup sequence to begin.
3. Press Reset again during the approximately one-second safe-mode window.

Safe mode prevents the QuantiFluorONE application from running while files are changed. Automatic reload is disabled, making this the preferred state for copying firmware, replacing JSON files, downloading CSV logs, and deleting old files.

### 5.2 Fast double-click: UF2 bootloader mode

Press the underside reset button twice in quick succession. The PyBadge display changes to the UF2 bootloader screen, and the computer mounts `PYBADGEBOOT` or `BADGEBOOT`.

PyBadge UF2 bootloader screen.

Typical contents of the PyBadge UF2 boot drive.

If `PYBADGEBOOT` appears when `CIRCUITPY` was intended, press Reset once to restart normally and repeat with slower timing.

## 6. Check or update the UF2 bootloader

A bootloader update is not required for every firmware installation.

1. Enter UF2 bootloader mode with a fast double-click.
2. Open `INFO_UF2.TXT` on `PYBADGEBOOT` or `BADGEBOOT`.
3. Read the installed bootloader version.

To install the supplied version 3.15.0 updater:

1. Copy `update-bootloader-arcade_pybadge-v3.15.0.uf2` to the UF2 boot drive.
2. Wait while the updater runs and the boot drive reappears.
3. Open `INFO_UF2.TXT` again and verify version 3.15.0.
4. Install CircuitPython 9.1.1 as described in the next section.

> **Do not copy** `bootloader-arcade_pybadge-v3.15.0.bin` to `PYBADGEBOOT` or `BADGEBOOT`. The BIN file is retained only for archival and technical recovery purposes.

## 7. Install CircuitPython 9.1.1

1. Confirm that the current `CIRCUITPY` contents have been backed up.
2. Enter UF2 bootloader mode with a **fast double-click**.
3. Copy `adafruit-circuitpython-pybadge-en_US-9.1.1.uf2` to `PYBADGEBOOT` or `BADGEBOOT`.
4. Wait for the board to restart automatically.
5. Confirm that the UF2 boot drive disappears and a new drive named `CIRCUITPY` appears.
6. Safely eject `CIRCUITPY` before disconnecting or restarting the instrument.

The stable RC2 archive records the tested runtime in `boot_out.txt` as:

```text
Adafruit CircuitPython 9.1.1 on 2024-07-22
Adafruit Pybadge with samd51j19
Board ID: pybadge
```

## 8. Clean installation of QuantiFluorONE stable RC2

This is the current recommended workshop procedure.

### 8.1 Prepare the firmware folder

1. Locate:

   ```text
   software/quantifluorone_firmware/
   QuantiFluorONE_Firmware_1.0.0-rc2-stable.zip
   ```

2. Extract the ZIP file to a normal folder on the computer.
3. Open the extracted outer folder named:

   ```text
   QuantiFluorONE_Firmware_1.0.0-rc2-stable
   ```

4. Leave the original ZIP file unchanged in the repository.

### 8.2 Empty `CIRCUITPY`

1. Confirm once more that the complete previous drive has been backed up.
2. Enter safe mode with the **slow double-click**.
3. Open the root of `CIRCUITPY`.
4. Select all existing files and folders on `CIRCUITPY`.
5. Delete the selected contents.
6. Confirm that no old firmware, library, configuration, state, calibration, or log files remain.

### 8.3 Copy the complete stable release

1. In the extracted stable-release folder, select **all files and folders inside** `QuantiFluorONE_Firmware_1.0.0-rc2-stable`.
2. Copy the complete selected contents to the **root of the empty `CIRCUITPY` drive**.
3. Do **not** copy the enclosing `QuantiFluorONE_Firmware_1.0.0-rc2-stable` folder itself. Files such as `boot.py` and `code.py` must be located directly in the root of `CIRCUITPY`.
4. Wait until copying is completely finished.
5. Compare the top-level files and folders with the extracted release folder.
6. Safely eject `CIRCUITPY`.
7. Press Reset once or power-cycle the device for a normal restart.

This full-copy procedure installs one complete, internally consistent release and avoids mixing files from different firmware generations.

## 9. First startup and hardware check

After the normal restart:

1. Confirm that the splash screen appears.
2. Confirm the display banner:

   ```text
   QuantiFluorONE v1.0 RC2
   ```

3. Confirm that no startup error screen is shown.
4. Open the SELECT menu.
5. Choose `LOAD MP CAL` only when the supplied or a compatible `quantifluorone_multipoint.json` is present.
6. Measure a fresh reagent blank with START.
7. Measure a test sample with A.

The display may show `cal=none c=uncalibrated` until a calibration is loaded or created. When the supplied provisional calibration is loaded, the status is marked `PROV`.

## 10. CSV and JSON write behaviour

The included `boot.py` provides two different file-system modes:

- with a USB data host connected, `CIRCUITPY` remains writable by the computer and read-only to the firmware;
- with a charger, power bank, or approved LiPo supply, the firmware can save blank state, calibration state, and CSV rows.

For firmware-generated writes:

1. safely eject and disconnect the USB data host;
2. power the PyBadge from a USB charger, power bank, or the approved LiPo supply;
3. restart the instrument normally;
4. perform the measurement or save operation.

Use the **slow double-click** whenever returning to computer-based file maintenance.

## 11. Updating or reinstalling the same supported release

Use the same clean procedure whenever a complete reinstall is needed:

1. back up `CIRCUITPY`;
2. enter safe mode with the slow double-click;
3. delete the complete contents of `CIRCUITPY`;
4. extract the unchanged stable RC2 archive;
5. copy all contents inside the extracted release folder to the root of `CIRCUITPY`;
6. safely eject and restart;
7. verify the RC2 display banner.

Do not merge a new installation with residual files from an older device state.

## 12. Troubleshooting

| Symptom | Likely cause or corrective action |
|---|---|
| No USB drive appears | check the power switch, USB port, and use a known data-capable cable |
| `PYBADGEBOOT` appears instead of `CIRCUITPY` | reset presses were too fast; press once to restart, then use the slow double-click if file maintenance is required |
| `CIRCUITPY` appears but files cannot be changed reliably | enter safe mode with the slow double-click before copying or deleting files |
| Device remains in safe mode | safely eject, then press Reset once or power-cycle |
| PyBadge repeatedly reloads while files are copied | use safe mode so that the application is not running during file maintenance |
| Firmware starts with missing-module or missing-file errors | repeat the clean installation and confirm that the complete release contents were copied to the root of `CIRCUITPY` |
| `boot.py` or `code.py` is not visible in the root of `CIRCUITPY` | the enclosing release folder was copied instead of its contents; empty the drive and repeat the installation |
| Firmware starts but does not log CSV while connected to a computer | expected project file-system behaviour; use a charger, power bank, or LiPo supply for firmware-side writes |
| Old measurement or calibration state reappears | residual files were retained or restored; repeat the clean installation and restore only confirmed compatible files |

The following screen indicates CircuitPython automatic reload or a soft reboot, not UF2 bootloader mode:

CircuitPython soft-reboot and automatic-reload screen.

## 13. References

- IO Rodeo. *Installing/upgrading CircuitPython and the bootloader.* https://blog.iorodeo.com/installing-upgrading-circuitpython-or-the-bootloader/
- IO Rodeo. *Installing/upgrading the firmware.* https://blog.iorodeo.com/installing-upgrading-the-firmware/
- Adafruit. *Installing CircuitPython — Adafruit PyBadge and PyBadge LC.* https://learn.adafruit.com/adafruit-pybadge/installing-circuitpython
- Adafruit. *Update the PyBadge Bootloader.* https://learn.adafruit.com/adafruit-pybadge/updating-the-bootloader
- Adafruit. *Troubleshooting — Safe Mode.* https://learn.adafruit.com/adafruit-pybadge/troubleshooting
- CircuitPython.org. *PyBadge downloads.* https://circuitpython.org/board/pybadge/

This chapter adapts the general IO Rodeo and Adafruit procedures to the current QuantiFluorONE hardware, enclosure, software versions, and the tested clean-installation workflow used for this instrument.

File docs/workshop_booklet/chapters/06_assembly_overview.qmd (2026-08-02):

# Assembly Overview

> **Status:** Draft

Content to be developed and reviewed.

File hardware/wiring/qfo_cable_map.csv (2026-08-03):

Connection | From | To | Cable | Status/notes
1 | PyBadge I2C/STEMMA interface | SparkFun PRT-15109 adapter | Qwiic/Grove adaptation | Confirmed topology; exact connector orientation to be photographed
2 | PRT-15109 adapter | PCA9546 upstream port | Four-conductor I2C/power cable | Exact length TBC
3 | PCA9546 downstream channel TBC | TSL2591 | STEMMA QT / Qwiic cable | Single detector; channel TBC
4 | PCA9546 branch or pass-through point TBC | ioRodeo radial_16mA board | STEMMA QT / Qwiic cable | No I2C address; exact branch and length TBC

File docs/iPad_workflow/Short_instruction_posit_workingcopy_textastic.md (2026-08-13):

TEXTASTIC
1. Write the content into qmd-files

WORKING COPY
1. Commit
2. Push

POSIT (Terminal)
1. Repository von Github aufrufen
2. Termianl wählen
3. cd /cloud/project/docs/workshop_booklet
4. quarto render --to pdf
5. cp \
  /cloud/project/docs/workshop_booklet/_book/DIY-QuantiFluorONE-dsDNA-Fluorometer.pdf \
  /cloud/project/00_DIY-QuantiFluorONE_Workshop_Handbook.pdf
  
6. cd /cloud/project
7. git add 00_DIY-QuantiFluorONE_Workshop_Handbook.pdf
8. git commit -m "Update rendered workshop handbook PDF"

POSIT (Console)
1. gert::git_push(repo = "/cloud/project")

WORKING COPY
1. PULL

# Workshop Booklet – Routine Workflow

## 1. QMD in Textastic ändern

Die gewünschte `.qmd`-Datei in Textastic bearbeiten und speichern.

Beispiel:

```text
docs/workshop_booklet/chapters/12_workshop_exercises_and_checklists.qmd
```

---

## 2. Änderungen mit Working Copy nach GitHub übertragen

In Working Copy:

1. Änderungen kontrollieren
2. Commit erstellen
3. Push nach GitHub

---

## 3. Änderungen in Posit Cloud holen

In der **R Console**:

```r
gert::git_pull(repo = "/cloud/project")
```

Danach prüfen, ob die geänderte `.qmd`-Datei in Posit tatsächlich den gewünschten Inhalt enthält.

---

## 4. Workshop Booklet neu rendern

Im **Terminal**:

```bash
cd /cloud/project/docs/workshop_booklet
quarto render --to pdf
```

Nach erfolgreichem Render liegt die neue PDF unter:

```text
docs/workshop_booklet/_book/DIY-QuantiFluorONE-dsDNA-Fluorometer.pdf
```

---

## 5. Gerenderte PDF kontrollieren

Die frisch gerenderte PDF in Posit öffnen und prüfen, ob die Änderungen korrekt übernommen wurden.

Erst wenn die PDF stimmt, fortfahren.

---

## 6. Neue PDF ins Wurzelverzeichnis kopieren

Im Terminal:

```bash
cp _book/DIY-QuantiFluorONE-dsDNA-Fluorometer.pdf ../../00_DIY-QuantiFluorONE_Workshop_Handbook.pdf
```

Anschließend die PDF im Wurzelverzeichnis öffnen und kurz kontrollieren.

---

## 7. PDF committen

Zurück ins Repository-Wurzelverzeichnis:

```bash
cd /cloud/project
```

Nur die neue PDF stagen:

```bash
git add 00_DIY-QuantiFluorONE_Workshop_Handbook.pdf
```

Commit erstellen:

```bash
git commit -m "Update corrected workshop handbook PDF"
```

---

## 8. PDF nach GitHub pushen

In der **R Console**:

```r
gert::git_push(repo = "/cloud/project")
```

---

## 9. Neue PDF auf das iPad holen

In Working Copy:

```text
Pull
```

Damit wird die neu gerenderte PDF aus GitHub auf das iPad übernommen.

---

# Kurzfassung

```text
Textastic
→ QMD ändern und speichern

Working Copy
→ Commit
→ Push

Posit Cloud / R Console
→ gert::git_pull(repo = "/cloud/project")

Posit Cloud / Terminal
→ cd /cloud/project/docs/workshop_booklet
→ quarto render --to pdf

Posit
→ neue PDF in _book öffnen und prüfen

Terminal
→ cp _book/DIY-QuantiFluorONE-dsDNA-Fluorometer.pdf ../../00_DIY-QuantiFluorONE_Workshop_Handbook.pdf

Terminal
→ cd /cloud/project
→ git add 00_DIY-QuantiFluorONE_Workshop_Handbook.pdf
→ git commit -m "Update corrected workshop handbook PDF"

Posit Cloud / R Console
→ gert::git_push(repo = "/cloud/project")

Working Copy
→ Pull

FERTIG
```

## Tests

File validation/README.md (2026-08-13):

# Validation

This directory contains the measurement data, comparison datasets, numerical results, and reproducible analysis used to assess the analytical performance of the DIY-QuantiFluorONE.

## Files

- `quantifluorone_log_v100rc2.csv`  
  Original DIY-QuantiFluorONE instrument log containing the measurements used for the current two-point and multipoint calibration and subsequent validation measurements.

- `quantus_diy_two_point_comparison.csv`  
  Paired Quantus and two-point-calibrated DIY-QuantiFluorONE results together with the corresponding DIY instrument values and analysis flags.

- `PROVISIONAL_calibration_MP_2026-07-24.csv`  
  Earlier provisional multipoint calibration dataset retained for documentation of the development history.

- `blank_performance_summary.csv`  
  Summary of the blank measurements used to characterize low-concentration performance.

- `diy_triplicate_concentration_summary.csv`  
  Concentration-level summary of the three technical TSL2591 readings within individual measurement cycles.

- `validation_statistics.csv`  
  Numerical statistics generated from the Quantus–DIY comparison analysis.

- `validation_and_analytical_performance.py`  
  Reproducible Python analysis of the paired Quantus–DIY comparison data.

- `requirements.txt`  
  Python dependencies required to run the analysis.

The figures generated by the analysis are stored under:

```text
docs/figures/rendered/ch10/
```

## Reproduce the Quantus–DIY comparison analysis

From the repository root:

```bash
python -m pip install -r validation/requirements.txt
python validation/validation_and_analytical_performance.py
```

## Interpretation of the 400 ng/µL point

The first paired result is the separately prepared nominal 400 ng/µL standard used as the upper anchor of the DIY two-point calibration. It returned 395 ng/µL when measured on the Quantus.

This point is shown in the comparison figures but excluded from the independent linear regression. The independent regression therefore uses the remaining 14 validation results.

## Important limitations

- Quantus was used as a commercial comparison instrument, not as a traceable reference method.
- Agreement with Quantus is therefore evidence of comparability, not by itself proof of analytical validity.
- The three TSL2591 readings within one measurement cycle are technical sensor repeats, not independently prepared assay replicates.
- Negative blank-corrected firmware values are displayed and reported as zero or below LOD.
- The primary LOD and LOQ estimates are based on ten independently prepared blank tubes.
- The current Python script reproduces the Quantus–DIY regression and agreement statistics. The LOD/LOQ summary figure uses precomputed blank-based values and does not recalculate those limits from the original blank measurements.

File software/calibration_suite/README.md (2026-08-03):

# Open Fluorometer Calibration Suite

This directory contains the browser-based calibration utility currently used with
the project.

Files:
- `Open_Fluorometer_Calibration_Suite_v7.2_Dynamic_Axis_Labels.html`
- `Open_Fluorometer_Calibration_Suite_v7.2_Dynamic_Axis_Labels.txt`

## Basic use

1. Open the HTML file in a modern desktop browser.
2. Load the calibration data or paste the relevant input.
3. Review the regression and calibration outputs.
4. Export or record the relevant calibration parameters for the device workflow.

The web app is stored in the repository for reproducibility and workshop use.

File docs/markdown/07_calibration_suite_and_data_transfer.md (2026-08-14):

---
document-status: "Current"
validation-status: "Validated configuration"
date: "2026-08-14"
---

## Purpose

The repository includes the current browser-based Calibration Suite as a local web app. This chapter covers the calibration workflow and the safe transfer of compatible calibration files to the QuantiFluorONE firmware.

## Repository location

The current files are stored in:

- `tools/calibration_suite/Open_Fluorometer_Calibration_Suite_v7.3.html`
- `tools/calibration_suite/Open_Fluorometer_Calibration_Suite_v7.3.txt`

## Basic workflow

1. Open the HTML file in a current desktop browser.
2. Load or paste the calibration data required by the app.
3. Review the plotted data and the resulting calibration output.
4. Record the calibration parameters required for the fluorometer workflow.
5. Store calibration exports together with the experimental metadata whenever possible.

## Recommended repository practice

- keep the web app under version control;
- record the active calibration-suite version in documentation and workshop notes;
- store example calibration data separately from the app itself;
- treat the web app as a reproducibility tool, not merely as a convenience file.

## Calibration-file transfer

1. Export and retain the complete calibration report and source data.
2. Transfer only a file that is explicitly compatible with QuantiFluorONE `QF1-1.0.0-rc2`.
3. Enter CircuitPython safe mode with the slow double-click before replacing JSON files on `CIRCUITPY`.
4. Back up the existing JSON file before replacement.
5. Safely eject `CIRCUITPY`, restart normally, and confirm the calibration status on the instrument.

---

⬅️ Previous Chapter: [Getting Started – Basic Operation and Menu Navigation](06_getting_started_basic_operation_and_menu_navigation.md)

📖 [Documentation Summary](SUMMARY.md)

➡️ Next Chapter: [Measurement Protocol](08_measurement_protocol.md)

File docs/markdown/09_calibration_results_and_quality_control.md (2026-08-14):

---
document-status: "Current"
validation-status: "Validated configuration"
date: "2026-08-14"
---

> **Scope:** This chapter provides the concise operational workflow for routine laboratory decisions. The theoretical and statistical basis of calibration, prediction intervals, LOD, and LOQ is described in Chapter 3.

## Calibration routes

Use one of the following calibration routes before measuring unknown samples.

| Calibration route | Preparation and evaluation | Instrument action | Appropriate use |
|---|---|---|---|
| On-instrument two-point calibration | Blank and one known standard | `SELECT → 2-PT CAL` | Rapid routine measurements within a limited working range |
| Multipoint calibration | Evaluate calibration CSV data in the Open Fluorometer Calibration Suite v7.3 Stable | Copy the accepted firmware-compatible JSON to `CIRCUITPY`, then use `SELECT → LOAD MP CAL` | Measurements requiring a defined calibration range, prediction error, LOD, LOQ, and documented model checks |
| Stored calibration | Review the stored calibration identity and status | `SELECT → CAL STATUS` | Continued work under unchanged and verified conditions |
| No valid calibration | Raw-signal inspection only | Do not report a concentration | Instrument checks and troubleshooting |

A calibration that loads successfully is not automatically suitable for the current samples.

## Use the Calibration Suite

The Calibration Suite is the primary tool for creating, evaluating, documenting, and exporting a multipoint calibration.

### Prepare the calibration dataset

Use standards prepared with the same:

- QuantiFluor® ONE dsDNA chemistry;
- sample and reagent volumes;
- tube type;
- incubation conditions;
- instrument configuration;
- gain and integration settings; and
- concentration basis intended for the unknown samples.

Import the calibration CSV into the Calibration Suite and confirm that the analytical-signal and reference-value columns were identified correctly.

For the standard assay described in Chapter 8, each tube contains:

- 1 µL standard or sample; and
- 200 µL QuantiFluor® ONE reagent.

The total assay volume is 201 µL.

### Evaluate the calibration

In the Calibration Suite:

1. Enter a unique calibration ID and the calibration date.
2. Confirm the reference-value basis and concentration unit.
3. Calculate the intended calibration model.
4. Inspect the calibration curve and residual plot.
5. Review replicate precision, recovery, outlier flags, and range coverage.
6. Review the slope, intercept, residual error, LOD, LOQ, and prediction statistics.
7. Confirm that no systematic trend, unexplained outlier, or unsuitable range remains.
8. Save or print the calibration report.

Do not accept a calibration from the coefficient of determination alone. A high \(R^2\) does not compensate for degraded standards, poor pipetting, an unsuitable range, or systematic residuals.

The current QF1-1.0.0-rc2 firmware imports an OLS multipoint calibration. Do not load another model type unless the firmware release documentation explicitly confirms compatibility.

### Export the operational calibration

After the model has been accepted:

1. Export the accepted multipoint calibration from the Calibration Suite as `quantifluorone_multipoint.json`.
2. Retain the original CSV, Calibration Suite report, and exported JSON together.
3. Do not edit individual coefficients manually after export.

The Calibration Suite report is the complete calibration record. The JSON file is the operational copy used by the fluorometer.

## Load and verify a multipoint calibration

To transfer an accepted multipoint calibration:

1. Connect the switched-on instrument to a computer with a USB data cable.
2. Make `CIRCUITPY` writable from the computer as described in Chapter 7.
3. Copy `quantifluorone_multipoint.json` to the root of `CIRCUITPY`.
4. Replace the previous file only when the new calibration has been checked and archived.
5. Safely eject and disconnect `CIRCUITPY`.
6. Power the instrument from its normal standalone power source.
7. Open `SELECT → LOAD MP CAL`.
8. Confirm the import.
9. Open `SELECT → CAL STATUS`.

Check at least:

- calibration ID;
- calibration type;
- calibration status;
- calibration range;
- concentration basis and unit;
- LOD and LOQ; and
- availability of the prediction error.

Measure and store a fresh reagent blank after loading a new calibration.

> Loading a new JSON does not replace the need for a current blank and passing QC samples.

## Check calibration validity before each batch

Use a stored or imported calibration only when all of the following are true:

- the calibration status is acceptable for the intended work;
- the calibration ID and date are documented;
- the assay, tube type, volumes, and concentration unit match;
- the instrument hardware and optical configuration are unchanged;
- the gain, integration time, and signal definition match;
- the standards and samples use the same concentration basis;
- the expected sample concentrations are covered by the calibration range;
- the calibration slope is positive;
- required LOD, LOQ, range, and error fields are available; and
- the laboratory-defined validity period has not expired.

Reject or replace the calibration when:

- the wrong file, assay, unit, or concentration basis was selected;
- required fields are missing;
- the expected samples fall outside the validated range;
- the instrument, optical holder, LED, filter, or sensor configuration has changed;
- reagent or standards are known to be degraded; or
- QC performance no longer supports the calibration.

## Measurement-batch sequence

Use the following sequence for each batch:

1. Confirm the active calibration under `CAL STATUS`.
2. Measure a fresh reagent blank.
3. Measure at least one independent QC sample.
4. Measure the unknown samples.
5. Repeat QC after a long interruption, suspected drift, or instrument change.
6. Measure a final QC sample when required by the laboratory procedure.
7. Review the complete batch before accepting results.

For a broad calibration range, preferably use low-, mid-, and high-level QC samples. QC material should be independent of the standards used to create the calibration whenever suitable material is available.

## Evaluate replicate measurements

### Three readings within one measurement cycle

The fluorometer uses three TSL2591 readings to calculate one measurement-cycle mean and standard deviation.

These are technical sensor repeats. They are not three independently prepared assays.

Check for:

- an unusually large standard deviation;
- a progressive increase or decrease;
- bubbles in the optical path;
- incomplete mixing;
- incorrect tube seating or orientation;
- fingerprints, droplets, or contamination on the tube; and
- movement or stray-light entry during measurement.

When a visible technical cause is present:

1. correct the problem;
2. remix gently when appropriate;
3. allow bubbles to disappear;
4. reposition or replace the tube; and
5. repeat the measurement.

Do not delete an individual reading without recording a technical reason.

### Independently prepared assay replicates

Independent replicates require separate pipetting of sample and reagent.

When replicate concentrations disagree:

1. check sample identity, calculations, pipetting, mixing, incubation, and tube placement;
2. remeasure the existing tubes;
3. prepare fresh independent replicates if disagreement remains; and
4. reject the result when no reproducible value can be obtained.

Near zero concentration, relative standard deviation may be misleading. Evaluate the absolute spread together with LOD and LOQ.

## Evaluate blank and QC samples

### Reagent blank

The blank must:

- use the same reagent and vessel type as the samples;
- contain no intentionally added dsDNA;
- be prepared and incubated with the batch; and
- remain within the laboratory-defined blank acceptance criterion.

An elevated or unstable blank may indicate contamination, carryover, bubbles, degraded reagent, an unsuitable calibration, or an optical problem.

When the blank fails:

1. prepare and measure a fresh blank;
2. inspect reagent, tubes, pipettes, and the optical chamber;
3. replace contaminated or degraded materials; and
4. repeat the calibration or affected batch when necessary.

Do not use a clearly invalid blank to correct unknown samples.

### Quality-control samples

A QC sample passes only when its result lies within a predefined acceptance interval.

The interval must be established before reviewing the batch and may be based on:

- an independently assigned target value;
- historical control data;
- an approved recovery range; or
- another documented laboratory criterion.

Do not create or widen QC limits after seeing the result.

When QC fails:

1. stop accepting unknown-sample results;
2. check the calibration, blank, dilution, pipetting, mixing, reagent, and tube placement;
3. repeat the QC measurement after correcting an identified technical problem;
4. prepare a fresh QC assay when required; and
5. repeat affected unknown samples if QC performance cannot be restored.

Results measured since the last passing QC sample are potentially invalid.

## Interpret concentration, prediction error, LOD, and LOQ

### Concentration basis

The current firmware reports the principal concentration on the original-sample basis defined by the calibration. The corresponding in-assay concentration may also be retained in the CSV output.

Do not mix original-sample and in-assay values.

The normal assay dilution caused by adding 1 µL sample to 200 µL reagent is already represented by the calibration metadata. Do not multiply the displayed original-sample result by 201.

Apply an additional factor only when the original unknown sample was deliberately diluted before assay preparation:

\[
c_\text{original}=c_\text{reported}\times F_\text{pre-dilution}
\]

Record the pre-dilution factor.

### Prediction error

For an imported multipoint calibration, the displayed `95% PI +/-` value is the half-width of the two-sided prediction interval for one analytical determination.

It is not the same as:

- the standard deviation of the three sensor readings;
- variation between independently prepared replicates; or
- uncertainty introduced by a manual pre-dilution.

Report concentration with its prediction error only when:

- a valid multipoint calibration is active;
- the prediction interval is available;
- the result lies within the calibration range;
- the result is at or above the LOQ; and
- blank, QC, and replicate criteria have passed.

### LOD and LOQ

Use the LOD and LOQ belonging to the active calibration and confirm their concentration basis.

| Result | Interpretation | Reporting action |
|---|---|---|
| Below LOD | The signal cannot be distinguished reliably from the blank | Report `< LOD` or `not detected`, according to the laboratory procedure |
| At or above LOD but below LOQ | dsDNA may be detected, but the concentration is not reliably quantifiable | Report `< LOQ` or `detected, not quantified` |
| At or above LOQ and within range | The result may be quantified if all other criteria pass | Report concentration and prediction error where available |
| Above the upper calibration limit | The result is outside the validated range | Dilute the original sample and repeat the complete assay |
| Below the lower validated range | The numerical estimate is outside the validated range | Do not report it as a normal quantitative result |

Negative blank-corrected values must not be reported as negative dsDNA concentrations. Report them according to the laboratory procedure, normally as `< LOD`.

## Accept, repeat, dilute, or reject

| Observation | Decision | Required action |
|---|---|---|
| Calibration valid; blank and QC pass; replicates agree; result at or above LOQ and within range | **Accept** | Report the result and record any pre-dilution |
| One tube shows unstable readings, bubbles, contamination, or incorrect placement | **Repeat measurement** | Correct the technical problem and remeasure the same tube |
| Independent assay replicates remain inconsistent | **Repeat assay preparation** | Prepare fresh independent replicates |
| Calibration is incompatible, expired, or incomplete | **Reject** | Load or create an acceptable calibration |
| Result is above range or the detector response is saturated | **Dilute and repeat** | Dilute the original sample, repeat the complete assay, and apply the recorded pre-dilution factor |
| Result is below LOQ | **Do not accept as a normal quantitative result** | Report according to the LOD/LOQ category |
| Blank fails | **Hold the batch** | Investigate and obtain an acceptable blank |
| QC fails | **Hold or reject affected results** | Correct the cause and repeat QC and affected samples |
| Wrong sample, dilution, reagent, protocol, unit, or calibration was used | **Reject** | Repeat the assay correctly |
| No technically justified and reproducible result can be obtained | **Reject** | Record the result as invalid and document the reason |

## Minimum documentation

Record at least:

- date and operator;
- instrument and firmware version;
- Calibration Suite version;
- calibration ID, date, type, status, and range;
- calibration report and operational JSON filename;
- reagent and standard identification;
- blank result;
- QC target, acceptance interval, and result;
- sample identifier;
- individual replicate results;
- measurement-cycle mean and standard deviation;
- prediction error where available;
- LOD and LOQ with concentration basis;
- pre-dilution factor;
- final reported result;
- acceptance decision; and
- reason for every repetition, dilution, exclusion, or rejection.

Retain the original data. Repeated or corrected measurements must not overwrite earlier results without traceability.

## Bench-side checklist

Before reporting a quantitative result, confirm:

- **Accepted calibration active?**
- **Calibration ID and range correct?**
- **Fresh blank passed?**
- **QC passed?**
- **Replicates consistent?**
- **Result at or above LOQ?**
- **Result within the calibration range?**
- **Prediction error available when required?**
- **Pre-dilution recorded?**
- **No unresolved technical fault?**

Only when all applicable checks pass may the result be accepted as quantitative.

---

⬅️ Previous Chapter: [Measurement Protocol](08_measurement_protocol.md)

📖 [Documentation Summary](SUMMARY.md)

➡️ Next Chapter: [Validation and Analytical Performance](10_validation_and_analytical_performance.md)

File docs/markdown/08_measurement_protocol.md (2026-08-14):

---
document-status: "Current"
validation-status: "Validated configuration"
date: "2026-08-14"
---

This short protocol is intended for participants with previous laboratory experience. All reagents required for the dsDNA assay are supplied with the Promega QuantiFluor® ONE dsDNA System. No reagent preparation is required.

## Materials and preparation

### Laboratory materials

- Powder-free latex gloves
- P2 or P10 pipette with sterile, DNA-free tips
- 200 µL pipette with sterile, DNA-free tips
- 1,000 µL pipette with sterile, DNA-free tips, if required for batch handling
- Promega QuantiFluor® ONE dsDNA System, 100 assays
- Thin-walled Promega E4941 0.5 mL PCR tubes
- Tube rack
- Timer
- Drawer or another dark place for light-protected incubation
- Notebook and pencil

### Equipment and digital access

- DIY-QuantiFluorONE-dsDNA-Fluorometer
- Smart device with access to the project GitHub repository and the Calibration Suite

## Clean working conditions

Work on a clean bench and wear fresh gloves. All pipette tips, PCR tubes, and other materials that come into contact with samples, standards, or reagents must be sterile and DNA-free.

The fluorometer, smart device, notebook, and pencil do not need to be sterile, but they must be kept clean and away from open tubes. Replace gloves immediately after possible contact with DNA-containing material.

## Assay setup

1. Label one PCR tube for the blank and additional tubes for standards, quality-control samples, and unknown samples.
2. Mix the QuantiFluor® ONE reagent and the DNA solutions gently before use. Avoid foaming.
3. Pipette 200 µL of QuantiFluor® ONE reagent into each tube.
4. Add 1 µL of blank solution, standard, quality-control sample, or unknown sample with a P2 or P10 pipette.
5. Close each tube and mix gently without creating bubbles.
6. Keep all tubes protected from direct light.

Use a fresh pipette tip for every transfer.

## Incubation

Place the prepared tubes in the rack and incubate them in a closed drawer or another dark place. Use the same incubation time for the blank, standards, quality-control samples, and unknown samples.

Incubate the prepared tubes for 5 minutes at room temperature, protected from light, in accordance with the Promega QuantiFluor® ONE dsDNA System instructions. Start the timer immediately after preparation of the last tube or prepare larger sample sets in clearly timed batches.

## Blank, calibration, and sample measurement

1. Switch on the DIY-QuantiFluorONE-dsDNA-Fluorometer.
2. Open the Calibration Suite on the smart device when calibration data must be loaded, checked, or evaluated.
3. Select or load the calibration intended for the current measurement series.
4. Insert the blank tube and perform the blank measurement.
5. Measure the calibration standards or quality-control samples when required.
6. Measure the unknown samples one after another.
7. Insert every tube in the same way and ensure that it is fully seated in the holder.
8. Record the displayed concentration and the accompanying quality information.

Do not measure tubes containing visible bubbles, droplets on the outside, or fingerprints in the optical measurement area. Clean or replace the tube before repeating the measurement.

## Recording and checking results

Record at least:

- Sample identification
- Date and time
- Calibration used
- Displayed dsDNA concentration
- Measurement error or uncertainty shown by the instrument
- LOD and LOQ shown by the instrument
- Dilution factor, if the original sample was diluted
- Relevant observations, such as bubbles or repeated measurements

Results below the LOD must not be reported as quantified concentrations. Results between the LOD and LOQ may be reported only as detected but not reliably quantified. Samples above the valid calibration range must be diluted and measured again.

When replicate measurements are performed, report the mean value and note any clearly inconsistent result.

## Cleaning and completion

Dispose of used tubes and pipette tips according to the local laboratory rules. Wipe the outside of the fluorometer and clean the working area. Do not allow liquid or cleaning agent to enter the fluorometer.

Store the QuantiFluor® ONE kit components according to the manufacturer’s instructions and ensure that all required measurement and calibration data have been saved before completing the measurement session.

## Quick reference

1. Put on fresh gloves and label the tubes.
2. Add 200 µL reagent to each tube.
3. Add 1 µL blank, standard, control, or sample.
4. Mix gently and incubate protected from light.
5. Blank the fluorometer and load the correct calibration.
6. Measure standards, controls, and samples.
7. Record concentration, error, LOD, LOQ, and any dilution.

---

⬅️ Previous Chapter: [Calibration Suite and Data Transfer](07_calibration_suite_and_data_transfer.md)

📖 [Documentation Summary](SUMMARY.md)

➡️ Next Chapter: [Calibration, Results and Quality Control](09_calibration_results_and_quality_control.md)

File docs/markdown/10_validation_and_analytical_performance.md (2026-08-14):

---
document-status: "Current"
validation-status: "Validated configuration"
date: "2026-08-10"
---

> **Operational calibration status:** ACTIVE  
> **Method performance status:** VERIFIED  
> **Operational range:** 0–400 ng/µL dsDNA  
> **Intended use:** Research, teaching, and workshop measurements

## Scope

The DIY fluorometer was evaluated under the final optical configuration and the standard QuantiFluor® ONE workflow of 1 µL sample plus 200 µL reagent.

Routine operation uses a two-point calibration consisting of a reagent blank and a nominal 400 ng/µL lambda-DNA standard. Analytical performance was assessed by comparison with a Promega Quantus Fluorometer, blank measurements, and the three consecutive TSL2591 readings recorded during each measurement cycle.

The Quantus was treated as a commercial comparison instrument rather than as a traceable reference method. It was used as an **independent external comparator**, not as a higher-ranked analytical truth.

## Calibration and comparison design

Two nominal 400 ng/µL lambda-DNA standards were prepared separately:

- one standard for the Quantus calibration;
- one standard for the DIY fluorometer calibration.

The DIY calibration standard returned 395 ng/µL when measured on the Quantus, corresponding to 98.75% recovery. The DIY calibration was not retrospectively changed from 400 to 395 ng/µL.

Fifteen paired values covered the blank-to-upper-standard interval. The 400 ng/µL DIY result is the upper two-point calibration anchor. It is shown in the figures but excluded from the independent linear regression.

## Why the Quantus is not treated as analytically superior

The comparison is arranged with the Quantus concentration on the x-axis only because an external comparator is required to assess the output of the two-point-calibrated DIY instrument.

This does **not** imply that the Quantus is analytically privileged, traceable, or error-free. It simply provides an independent comparison scale. The resulting figures answer the practical question:

> *How closely do the concentrations reported by the two-point-calibrated DIY fluorometer follow an independently measured comparator across the tested range?*

## Linearity of the two-point-calibrated DIY results

The most direct practical linearity check is the comparison of the concentrations reported by the two-point-calibrated DIY fluorometer with the independently obtained Quantus concentrations.

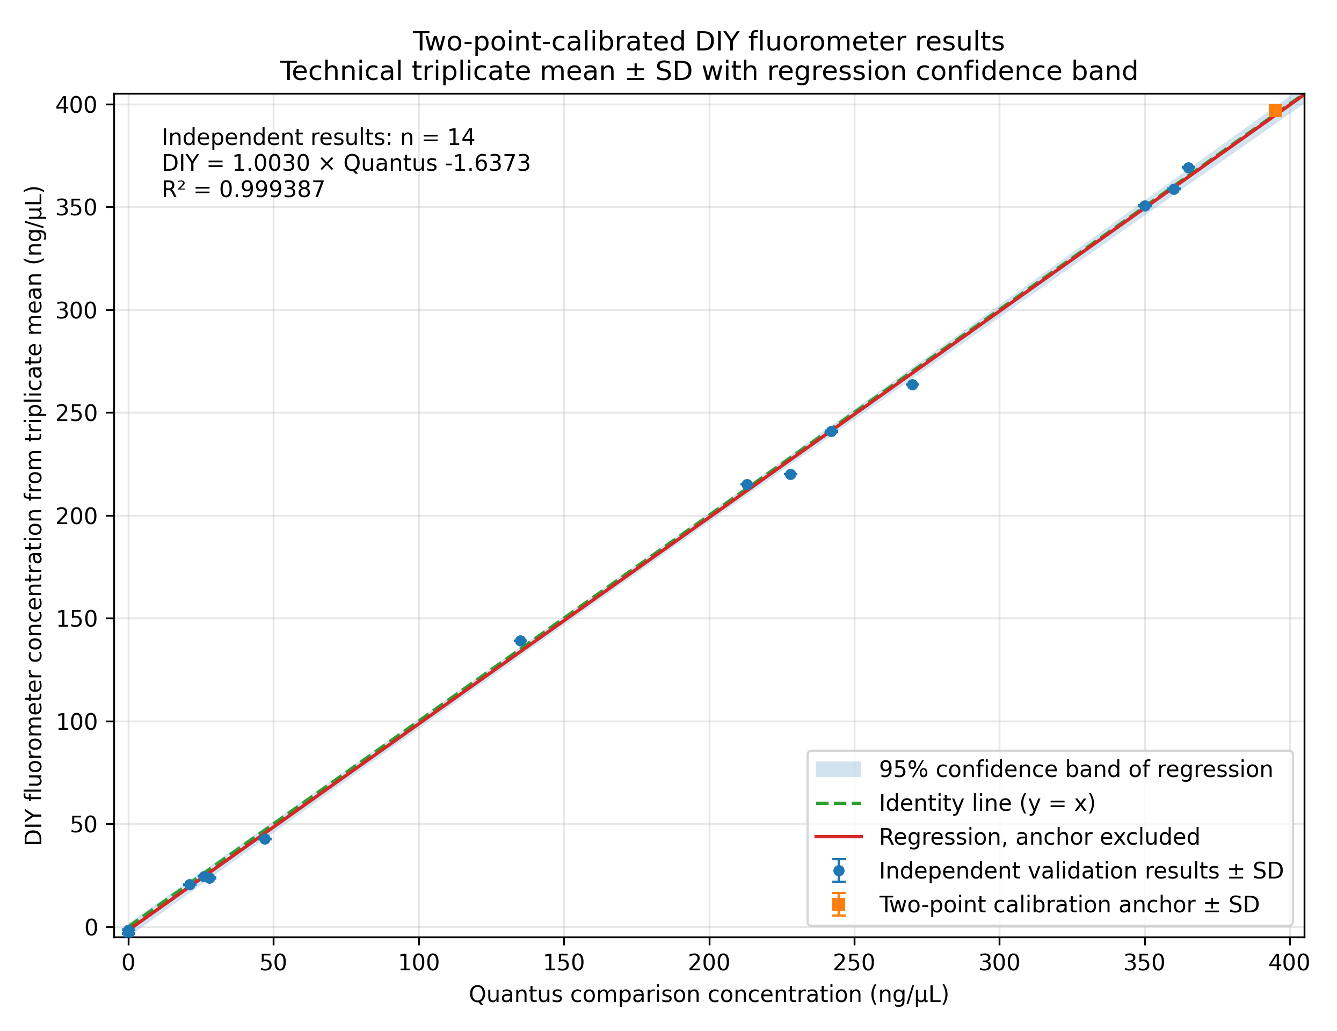
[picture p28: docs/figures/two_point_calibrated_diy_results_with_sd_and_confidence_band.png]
Two-point-calibrated DIY fluorometer results shown as technical triplicate mean ± SD. Marker size was reduced so that the error bars remain visible. The shaded band is the 95% confidence band of the independent linear regression. The square identifies the upper calibration anchor.


For the 14 independent results:

$$
c_{\mathrm{DIY}}=1.0030\,c_{\mathrm{Quantus}} - 1.6373
$$
$$
R^2=0.999387
$$

The slope was close to 1, the intercept was close to 0, and no systematic curvature was evident over the tested interval.

The same technical-repeat data can also be visualized with 95% confidence intervals for the three technical readings:

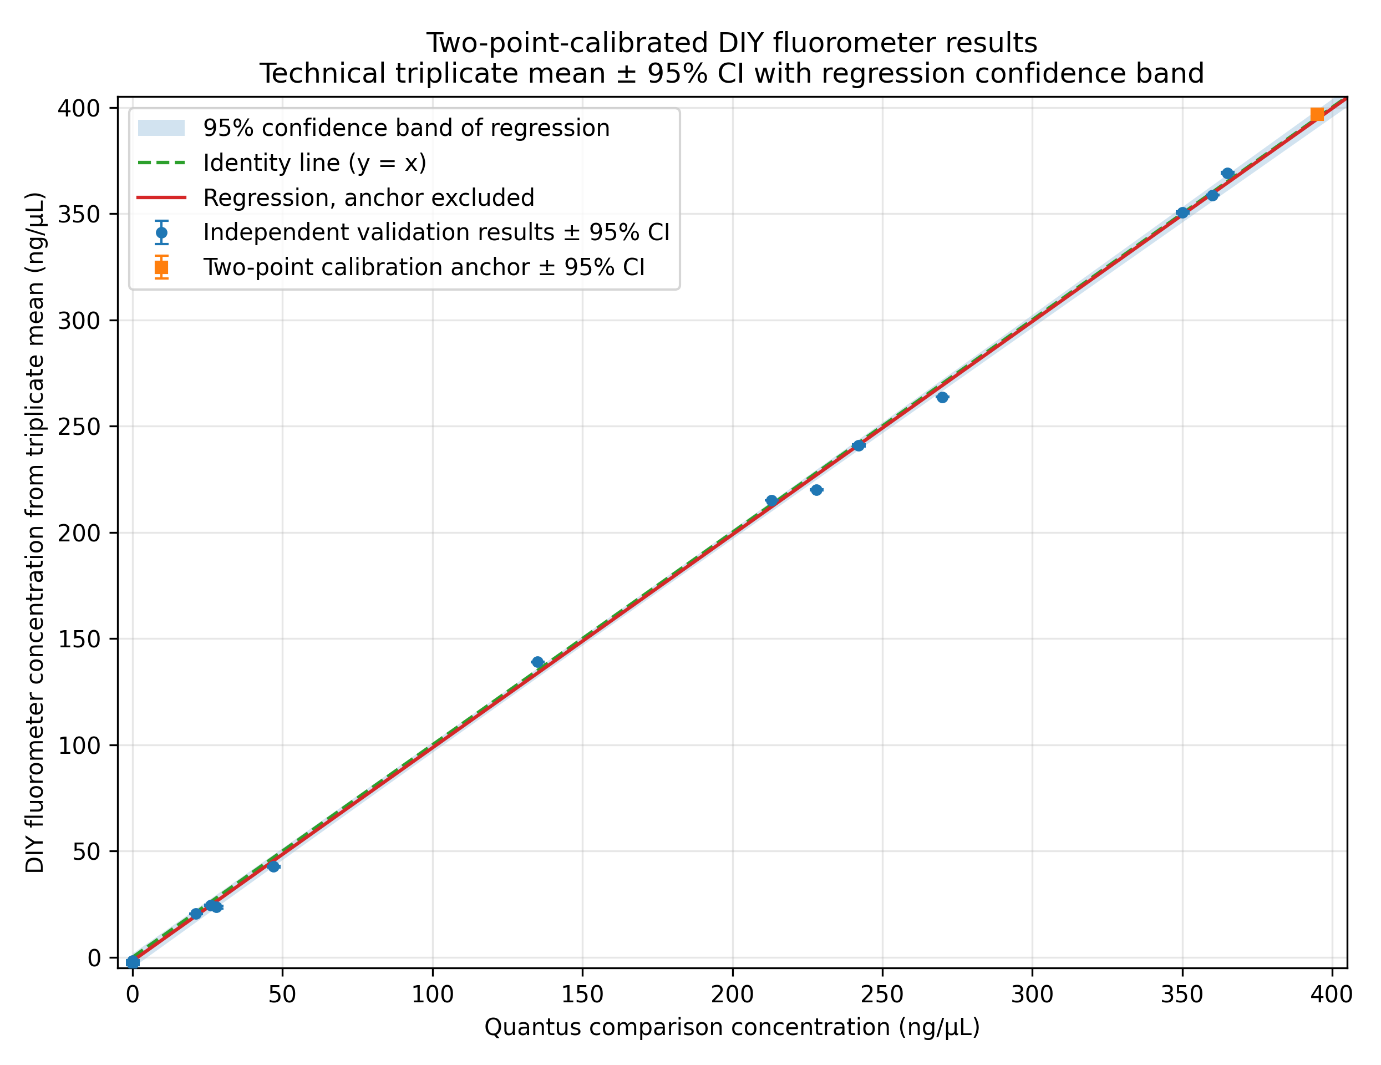
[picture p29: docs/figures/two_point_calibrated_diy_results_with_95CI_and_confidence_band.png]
Two-point-calibrated DIY fluorometer results shown as technical triplicate mean ± 95% confidence interval. The shaded band is again the 95% confidence band of the independent regression. These intervals describe the uncertainty of the three consecutive sensor readings within one measurement cycle; 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


A formal curvature assessment such as a Mandel fitting test would be more defensible with independent replicate preparations per concentration level. In the present dataset, the triplicate readings are technical sensor repeats rather than independent assay replicates. They support the visual conclusion of linearity and short-term repeatability, but they should not be overinterpreted as full replicate-level evidence of non-linearity testing.

For transparency, including the upper calibration anchor gives:

$$
c_{\mathrm{DIY}}=1.0067\,c_{\mathrm{Quantus}} - 1.9467
$$
$$R^2=0.999415$$

## Agreement with the Quantus

A Bland–Altman plot is a useful complement to the linearity figure because it answers a different question: not *Is the relation linear?*, but *How large is the bias and how wide is the agreement interval between the two devices?*

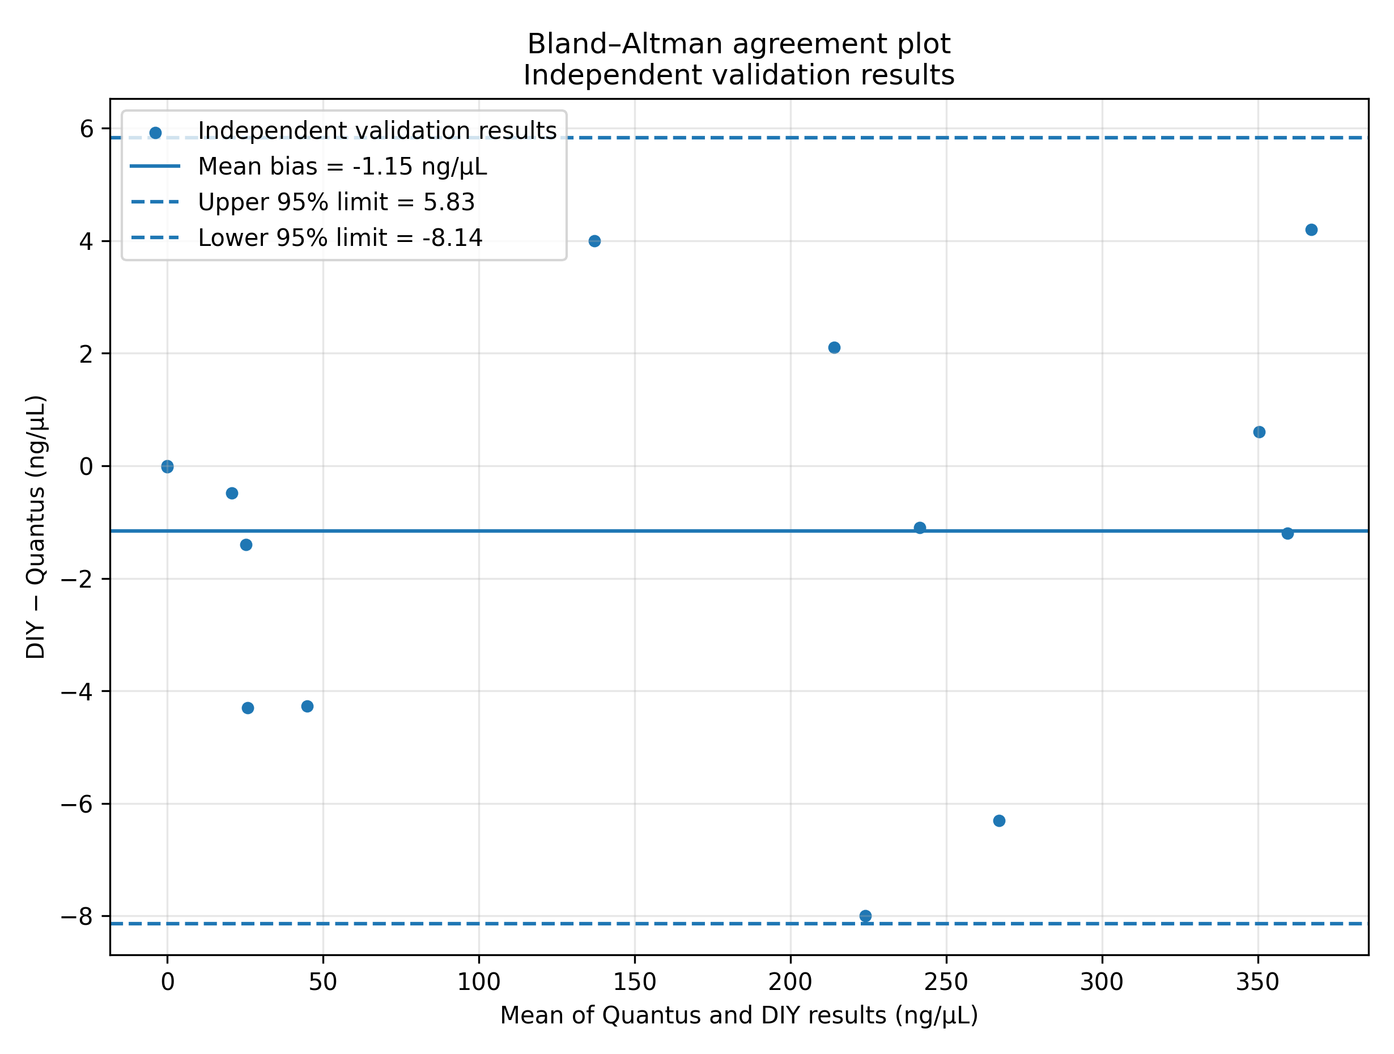
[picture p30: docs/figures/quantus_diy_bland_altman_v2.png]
Bland–Altman agreement plot for the independent validation results. The solid line marks the mean bias, and the dashed lines mark the approximate 95% limits of agreement.


The independent comparison results gave:

| Statistic | Result |
|---|---:|
| Independent paired results | 14 |
| Mean bias, DIY − Quantus | -1.15 ng/µL |
| Median bias, DIY − Quantus | -0.79 ng/µL |
| Mean absolute error | 2.71 ng/µL |
| Root mean squared error | 3.62 ng/µL |
| Mean absolute relative difference above the primary LOQ | 3.79% |
| Approximate 95% limits of agreement | -8.14 to 5.83 ng/µL |

The Bland–Altman plot is therefore useful and appropriate here, but as a complement to the linearity assessment rather than a replacement for it.

## What an RFU-versus-calculated-concentration plot can and cannot show

A plot of RFU versus the concentration calculated from the same two-point equation is useful as an **internal arithmetic-consistency check**. In the present device log, the corresponding relationship for rows 11–24 is:

$$
RFU = 102.672895\,c - 0.002265
$$

with: $$R^2 = 0.999999999995$$

This near-perfect linearity is expected because the concentration values are mathematically derived from the same RFU values and the same two-point calibration equation.

Therefore, an RFU-versus-calculated-concentration plot is valuable for checking that the firmware applied the calibration equation correctly, but it is **not independent evidence of analytical linearity**. Independent linearity must instead be judged against an external reference scale or assigned concentration levels.

## Blank performance, LOD, and LOQ

The primary blank study used ten independently prepared reagent-blank tubes. Each tube was measured in one complete cycle of three consecutive sensor readings.

The blank-based evaluation follows the project framework already described in Chapter 3 and uses the practical decision workflow documented here. The reporting of LOD and LOQ is aligned with the analytical concepts underlying **DIN 32645** and the calibration/working-range framework described in **DIN 38402-A51**.

| Primary blank result | Value |
|---|---:|
| Independent blank tubes | 10 |
| Mean VIS signal | 9,557.563 counts |
| SD of blank-cycle means | 126.514 counts |
| LOD, original-sample basis | 7.902 ng/µL |
| LOQ, original-sample basis | 23.946 ng/µL |
| LOD, in-assay basis | 0.03931 ng/µL |
| LOQ, in-assay basis | 0.11913 ng/µL |

Two additional independently prepared blanks were later measured in eleven repeated cycles each. They produced confirmatory estimates of 7.027 ng/µL for the LOD and 21.294 ng/µL for the LOQ. These 22 cycles represent repeated measurements of two blank preparations and are not counted as 22 independent blanks.

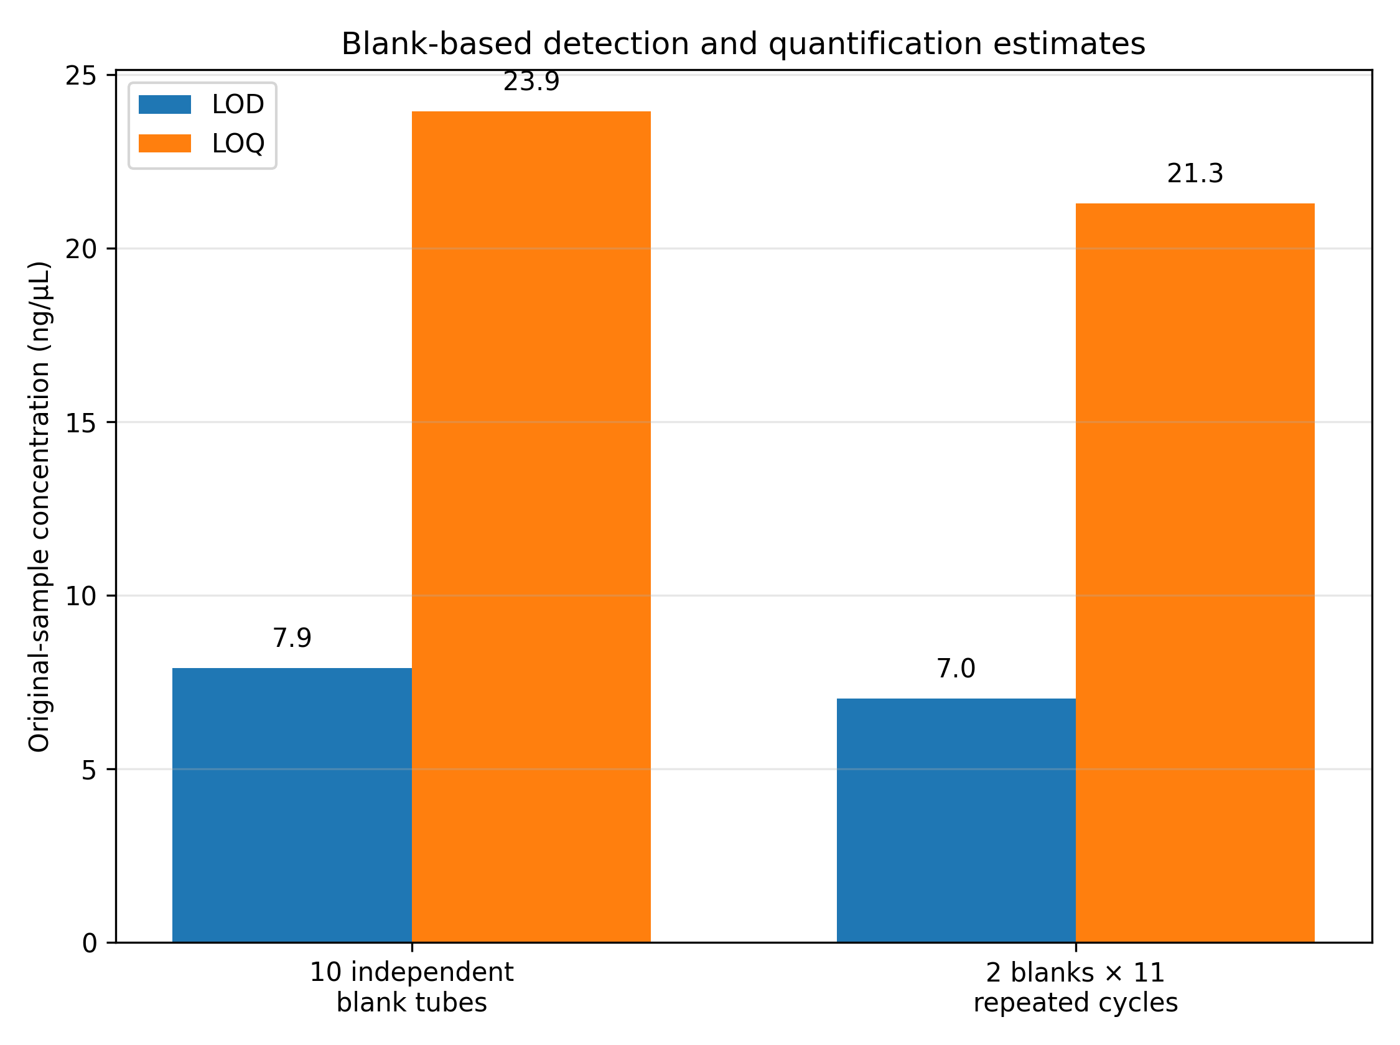
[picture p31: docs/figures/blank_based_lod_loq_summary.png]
Primary and confirmatory blank-based LOD and LOQ estimates.


For concise operational use, the project uses approximately:

- **LOD: 8 ng/µL**
- **LOQ: 24 ng/µL**

## Technical repeatability and sensor channels

Every measurement cycle contains three consecutive TSL2591 readings of the same assay tube.

In the final repeated-blank series:

- median within-cycle VIS CV: 0.033%;
- maximum within-cycle VIS CV: 0.348%.

These values demonstrate very good short-term sensor repeatability. They do not represent independent assay-preparation precision.

The analytical signal is calculated as: $$VIS = FULL - IR$$

The IR channel is therefore included in every blank, RFU, and concentration calculation. In the evaluated blank data, IR subtraction slightly reduced rather than increased overall signal variability; the IR channel was not the dominant observed source of variation.

## Operational range and reporting

The operational calibration range is **0–400 ng/µL**. LOD and LOQ define result categories within this range and do not remove the blank endpoint from the stated range.

| Result | Reporting action |
|---|---|
| Blank or below approximately 8 ng/µL | Report as `< LOD` or not detected |
| Approximately 8 to below 24 ng/µL | Report as detected but below LOQ |
| Approximately 24 to 400 ng/µL | Report quantitatively when calibration, blank, and QC requirements pass |
| Above 400 ng/µL or sensor saturation | Dilute the original sample and repeat the assay |

## Routine quality control

Routine measurements continue to use an active two-point calibration. At least one independently prepared control standard should be measured before unknown samples are accepted.

A mid-range control is the most important routine check. Low- and high-level controls can be added where required.

The method-performance status and the current operational-calibration status must remain separate:

```text
Operational calibration status: ACTIVE
Method performance status: VERIFIED
Operational range: 0–400 ng/µL
```

## Conclusion

Under the tested configuration and assay conditions, the DIY fluorometer showed:

- a linear two-point-calibrated response over 0–400 ng/µL;
- close agreement with the Quantus comparison instrument;
- blank-based LOD and LOQ estimates of 7.9 and 23.9 ng/µL;
- very good short-term technical repeatability; and
- valid unsaturated measurements through the 400 ng/µL upper calibration endpoint.

The method is suitable for research, teaching, and workshop measurements. It is not intended for clinical diagnostic use.

## Reproducibility files

The analysis source and data are stored under:

```text
validation/
```

Additional processed data for the technical-triplicate concentration statistics are stored in:

```text
validation/processed_data/diy_triplicate_concentration_summary.csv
```

---

⬅️ Previous Chapter: [Calibration, Results and Quality Control](09_calibration_results_and_quality_control.md)

📖 [Documentation Summary](SUMMARY.md)

➡️ Next Chapter: [Troubleshooting](11_troubleshooting.md)

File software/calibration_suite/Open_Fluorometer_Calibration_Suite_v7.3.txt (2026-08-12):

<!doctype html>
<html lang="en">
<head>
<meta charset="utf-8">
<meta name="viewport" content="width=device-width, initial-scale=1">
<title>Open Fluorometer/Photometer Calibration Suite v7.3 Standards-Audit</title>
<style>
:root{--navy:#18324a;--blue:#2f5f87;--muted:#66717c;--line:#d7dee5;--soft:#eef3f6;--bg:#f4f6f8;--good:#28724b;--bad:#a44242;--warn:#8a5b12}
*{box-sizing:border-box} html{-webkit-text-size-adjust:100%} body{font-family:Arial,-apple-system,BlinkMacSystemFont,"Segoe UI",Roboto,sans-serif;margin:0;background:var(--bg);color:#1d2732;line-height:1.45}
.wrap{max-width:1280px;margin:auto;padding:clamp(12px,2vw,24px)} h1{font-size:clamp(24px,3vw,32px);margin:0;color:var(--navy)} h2{font-size:18px;margin:0 0 10px;color:var(--navy)} h3{color:var(--navy)}
.subtitle{color:var(--muted);margin:3px 0}.badge{display:inline-block;margin-top:8px;padding:4px 9px;border:1px solid #bfcbd5;border-radius:999px;background:#fff;color:var(--navy);font-size:12px;font-weight:700}
.card{background:#fff;border:1px solid var(--line);border-radius:12px;padding:16px;margin:14px 0;box-shadow:0 2px 8px #18324a10}.grid{display:grid;grid-template-columns:1fr;gap:14px}@media(min-width:860px){.grid.two{grid-template-columns:1fr 1fr}}@media(min-width:900px){.grid.three{grid-template-columns:repeat(3,1fr)}}
label{display:block;font-weight:700;font-size:13px;margin-top:10px;margin-bottom:4px} textarea,input,select,button{font:inherit;border:1px solid #b9c5cf;border-radius:8px;padding:10px} textarea{width:100%;min-height:220px;font-family:Consolas,"Courier New",monospace}input,select{width:100%}
button{background:var(--blue);color:#fff;border-color:var(--blue);cursor:pointer;margin:7px 6px 0 0;min-height:42px}.secondary{background:var(--soft);color:var(--navy);border-color:#cbd5dd}button:disabled{opacity:.55;cursor:not-allowed}.small{font-size:13px;color:var(--muted)}.ok,.pass{color:var(--good);font-weight:700}.bad,.fail{color:var(--bad);font-weight:700}.warn{color:var(--warn);font-weight:700}.mono,pre{font-family:Consolas,"Courier New",monospace}pre{background:#f1f4f6;border:1px solid var(--line);border-radius:8px;padding:11px;overflow:auto;white-space:pre-wrap}
table{border-collapse:collapse;width:100%;font-size:13px}th,td{padding:8px;border-bottom:1px solid #dce2e8;text-align:right;white-space:nowrap}th:first-child,td:first-child{text-align:left}th{background:#eef2f5;position:sticky;top:0;color:var(--navy)}.scroll{overflow:auto;max-height:440px}.selected-row{background:#eef5f9}
canvas{width:100%;height:auto;border:1px solid var(--line);border-radius:9px;background:#fff;display:block}.resultbox{margin-top:12px;padding:12px;border:1px solid #a9d8b7;border-radius:8px;background:#eef9f1;color:#174d31}.report-note{border-left:4px solid var(--blue);background:#f1f6fa;padding:10px;border-radius:7px}.audit-note{border-left:4px solid var(--good);background:#f2faf5;padding:10px;border-radius:7px}.caution-note{border-left:4px solid var(--warn);background:#fff8ea;padding:10px;border-radius:7px}
.toolbar{display:flex;flex-wrap:wrap;gap:8px;align-items:center}.toolbar button{margin:0}.statusbar{display:grid;grid-template-columns:repeat(2,1fr);gap:8px;margin:18px 0 4px;padding:13px;border:1px solid var(--line);border-radius:10px;background:#e9eef2}@media(min-width:700px){.statusbar{grid-template-columns:repeat(4,1fr)}}@media(min-width:1050px){.statusbar{grid-template-columns:repeat(7,1fr)}}.sl{display:block;font-size:11px;text-transform:uppercase;color:var(--muted)}.sv{display:block;font-size:13px;color:var(--navy);font-weight:700;overflow-wrap:anywhere}.statbox{border:1px solid var(--line);border-radius:9px;padding:12px;background:#fafcfd}.pill{display:inline-block;background:var(--soft);color:var(--navy);border-radius:999px;padding:5px 10px;margin:3px;border:1px solid #d5dfe6}
@media print{body{background:#fff;color:#000}.wrap{max-width:none;padding:0}.card{box-shadow:none;break-inside:avoid;margin:8px 0;border:1px solid #ccc}.no-print,button,input[type=file],textarea{display:none!important}.statusbar{display:none}.grid.two,.grid.three{grid-template-columns:1fr 1fr}canvas{width:100%!important;height:auto!important;max-height:330px}.print-title{display:block!important}h1{font-size:23px}h2{font-size:15px}}.print-title{display:none}
</style>
</head>
<body><div class="wrap">
<header>
<div class="print-title"><h1>Open Fluorometer Calibration Report</h1></div>
<h1>Open Fluorometer Calibration Suite</h1>
<p class="subtitle">Transparent calibration, model diagnostics and standards-audit reporting for open fluorometry and photometry.</p>
<span class="badge" id="version-badge">v7.3 Standards-Audit · audit release</span>
<div class="toolbar no-print" style="margin-top:10px"><button id="print-report">Print / save report as PDF</button><button id="selftest" class="secondary">Run openDIN standards self-test</button></div>
</header>

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

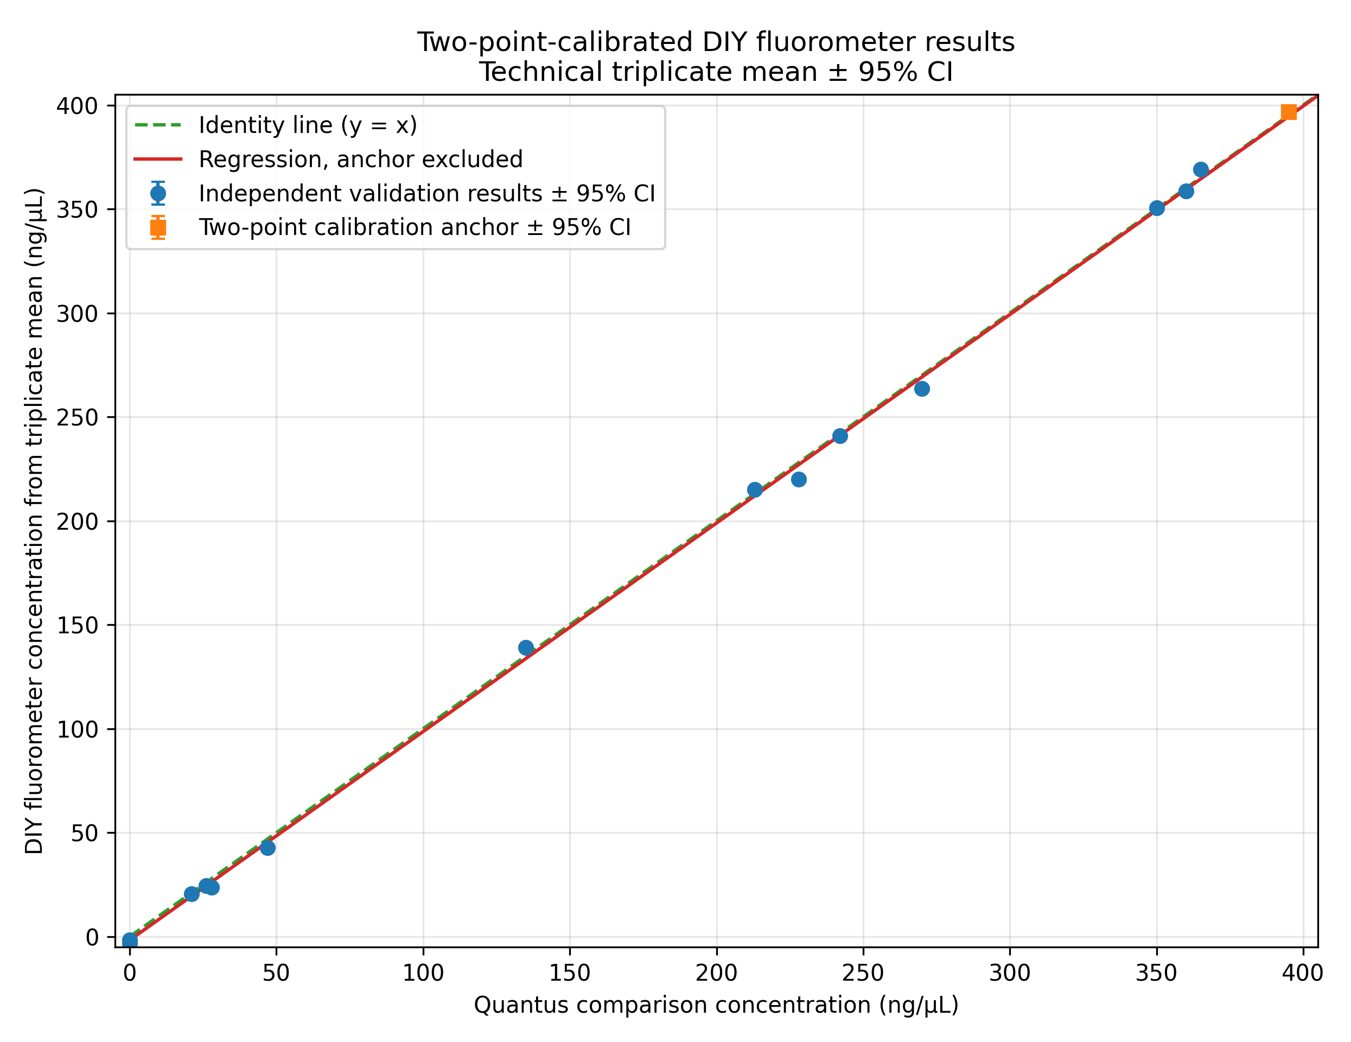
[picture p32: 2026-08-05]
docs/figures/two_point_calibrated_diy_results_with_95CI.png

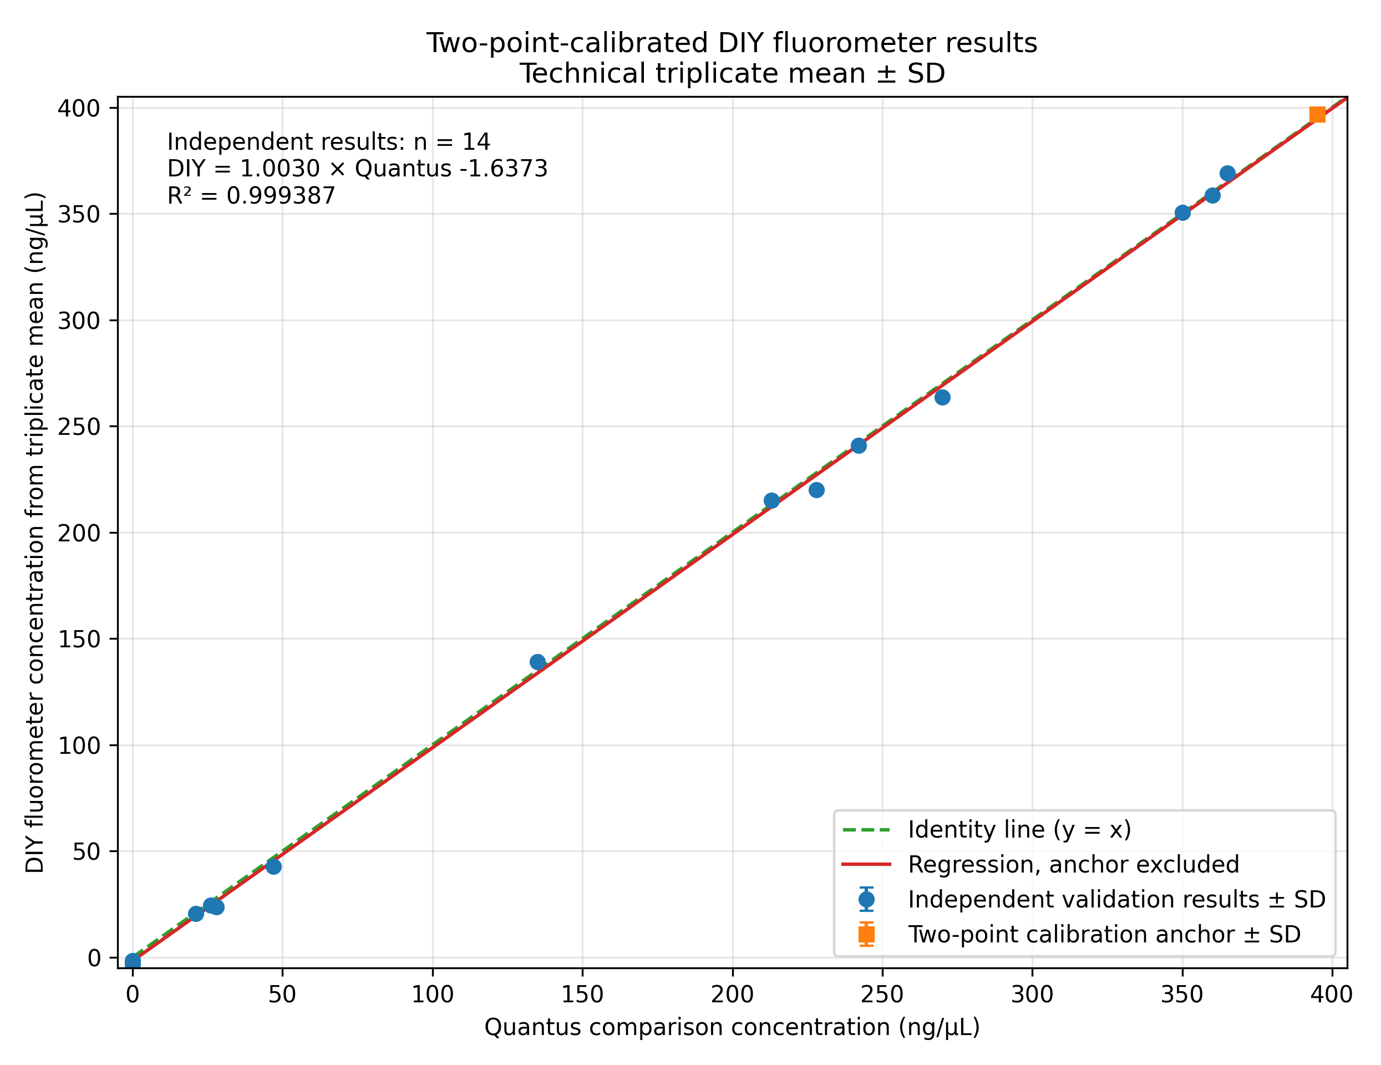
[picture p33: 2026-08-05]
docs/figures/two_point_calibrated_diy_results_with_sd.png

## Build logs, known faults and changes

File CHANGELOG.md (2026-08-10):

# Changelog

All notable changes to the DIY-QuantiFluorONE-dsDNA-Fluorometer will be documented here.

## [Unreleased]

No unreleased changes at this time.

## [1.0.0] - 2026-08-10

### Added
- Final workshop booklet for the 2026 eDNA workshop within the STABLE Project.
- Validated analytical-performance documentation for the documented hardware and assay configuration.
- Final hardware, software, calibration, validation, references, and workshop documentation structure.
- MIT License and completed citation metadata.
- Prominent workshop entry points through the GitHub Markdown documentation and downloadable PDF booklet.
- Source and provenance references for ioRodeo, DIYNAFLUOR, Adafruit, Promega, PySpectrometer2, standards, optical filters, and related hardware.

### Changed
- Consolidated the workshop documentation into the final 14-chapter structure.
- Updated project metadata and repository documentation for release `v1.0.0`.
- Updated analytical status terminology to distinguish operational calibration status from method-performance status.
- Updated the documented optical geometry to one TSL2591 sensor fixed at 90° to the excitation axis.
- Simplified the repository structure and removed obsolete development scaffolds and redundant directories.
- Updated the software layout to one supported QuantiFluorONE firmware package under `software/`.
- Updated the Calibration Suite and calibration-transfer documentation to the validated workflow.
- Updated references, acknowledgements, third-party attribution, and mechanical-source documentation.

### Verified
- Operational calibration status: `ACTIVE`.
- Method performance status: `VERIFIED`.
- Operational range: 0–400 ng/µL dsDNA.
- Documented firmware environment: CircuitPython 9.1.1 and QuantiFluorONE QF1-1.0.0-rc2.
- Calibration Suite: v7.2 Stable.

## [0.1.2-draft.1] - 2026-08-02

### Changed
- Renamed the project from `QuantiFluorONE` to `DIY-QuantiFluorONE-dsDNA-Fluorometer`.
- Introduced the controlled short name `DIY-QFO` and repository slug `diy-quantifluorone-dsdna-fluorometer`.
- Clarified the distinction between the DIY instrument and the Promega QuantiFluor® ONE dsDNA System.
- Updated document titles, metadata, identifiers, booklet sources, and citation metadata.

## [0.1.1-draft.1] - 2026-08-02

### Changed
- Corrected the optical architecture to a single TSL2591 sensor at approximately 90° to the excitation beam.
- Removed all 180° reference-channel and fluorescence/reference-ratio terminology.
- Defined the calibration response as the blank-corrected 90° fluorescence signal.

## [0.1.0-draft.1] - 2026-08-02

### Added
- Initial repository and documentation structure.

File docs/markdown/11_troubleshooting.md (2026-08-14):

---
document-status: "Current"
validation-status: "Validated configuration"
date:  "2026-08-14"
---

This chapter summarizes the most common operational problems that may occur during assembly, firmware installation, calibration, and routine measurements. It is intended as a practical troubleshooting guide for workshop participants and laboratory users. More detailed background information is provided in the previous chapters.

## Hardware

| Symptom | Possible cause | Recommended action |
|---|---|---|
| Display remains dark | Battery discharged | Recharge the PyBadge or connect USB power. |
| Device does not start | CircuitPython not installed correctly | Repeat the firmware installation (Chapter 5). |
| LED does not illuminate | Loose cable or incorrect connector | Verify all wiring and connector orientation. |
| Sensor not detected | Qwiic/STEMMA cable disconnected or I²C scan unsuccessful | Check the cable, connectors, and I²C connections, then restart the instrument. |
| Very low fluorescence signal | Optical filters installed incorrectly | Verify the orientation and seating of both optical filters. |
| Signal permanently saturated | Light shield open, optical light leak, or excessive sample signal | Close the light shield and inspect the optical path. If the sample remains above range, dilute it and repeat the assay. |

## Firmware and Software

| Symptom | Possible cause | Recommended action |
|---|---|---|
| Calibration cannot be loaded | Missing or incompatible JSON file | Export the calibration again using the Calibration Suite. |
| Calibration import fails | Invalid JSON format | Validate the calibration file before copying it to the device. |
| Device reports "uncalibrated" | No calibration selected | Load a valid calibration before measuring samples. |
| Device freezes during startup | Incomplete firmware installation | Reinstall the firmware according to Chapter 5. |

## Calibration

| Symptom | Possible cause | Recommended action |
|---|---|---|
| Blank values unstable | Ambient light or contaminated PCR tube | Repeat the blank measurement using a clean tube under stable conditions. |
| Calibration rejected | Standards prepared incorrectly | Prepare fresh standards and repeat the calibration. |
| Unknown outside calibration range | Sample concentration exceeds the validated range | Dilute the sample and repeat the measurement. |
| High calibration uncertainty | Pipetting errors or degraded standards | Prepare fresh standards and recalibrate. |

## Measurement

| Symptom | Possible cause | Recommended action |
|---|---|---|
| Large replicate variation | Air bubbles or insufficient mixing | Mix gently and remove visible bubbles before measurement. |
| Negative or below-zero calculated result | Sample signal below the stored blank or blank mismatch | Measure a fresh reagent blank and verify the calibration. Do not report a negative dsDNA concentration; apply the LOD/LOQ reporting rules from Chapter 9. |
| Unexpectedly low concentration | Pipetting error or degraded reagent | Verify pipetting accuracy and reagent quality. |
| Unexpectedly high concentration | Sample contamination | Prepare a fresh aliquot and repeat the measurement. |
| Measurement exceeds calibration range | Sample concentration above the validated range | Dilute the sample and repeat the analysis. |

## Calibration Suite

| Symptom | Possible cause | Recommended action |
|---|---|---|
| CSV file cannot be imported | Incorrect or unsupported CSV structure | Check the delimiter, column headers, decimal format, and required calibration-data columns. |
| Calibration model unavailable | Insufficient calibration points | Acquire additional standards covering the required concentration range. |
| Exported JSON rejected | Calibration incomplete | Complete the calibration workflow before exporting. |

## Preventive Maintenance

To ensure reproducible analytical performance:

- keep the optical compartment clean and free of dust;
- inspect optical filters regularly for contamination or damage;
- use clean PCR tubes for every measurement;
- ensure that the selected power source is sufficiently charged before extended measurement sessions;
- periodically verify the instrument using a quality-control sample.

## Quick Troubleshooting Guide

| Problem | Section |
|---|---|
| Device does not start | Hardware |
| LED or sensor not working | Hardware |
| Calibration cannot be loaded | Firmware and Software |
| Calibration rejected | Calibration |
| Unexpected measurement results | Measurement |
| CSV or JSON problems | Calibration Suite |

---

⬅️ Previous Chapter: [Validation and Analytical Performance](10_validation_and_analytical_performance.md)

📖 [Documentation Summary](SUMMARY.md)

➡️ Next Chapter: [Workshop Review, Quality Check and Further Applications](12_workshop_exercises_and_checklists.md)

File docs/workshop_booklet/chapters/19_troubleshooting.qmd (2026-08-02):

# Troubleshooting

> **Status:** Draft

Content to be developed and reviewed.

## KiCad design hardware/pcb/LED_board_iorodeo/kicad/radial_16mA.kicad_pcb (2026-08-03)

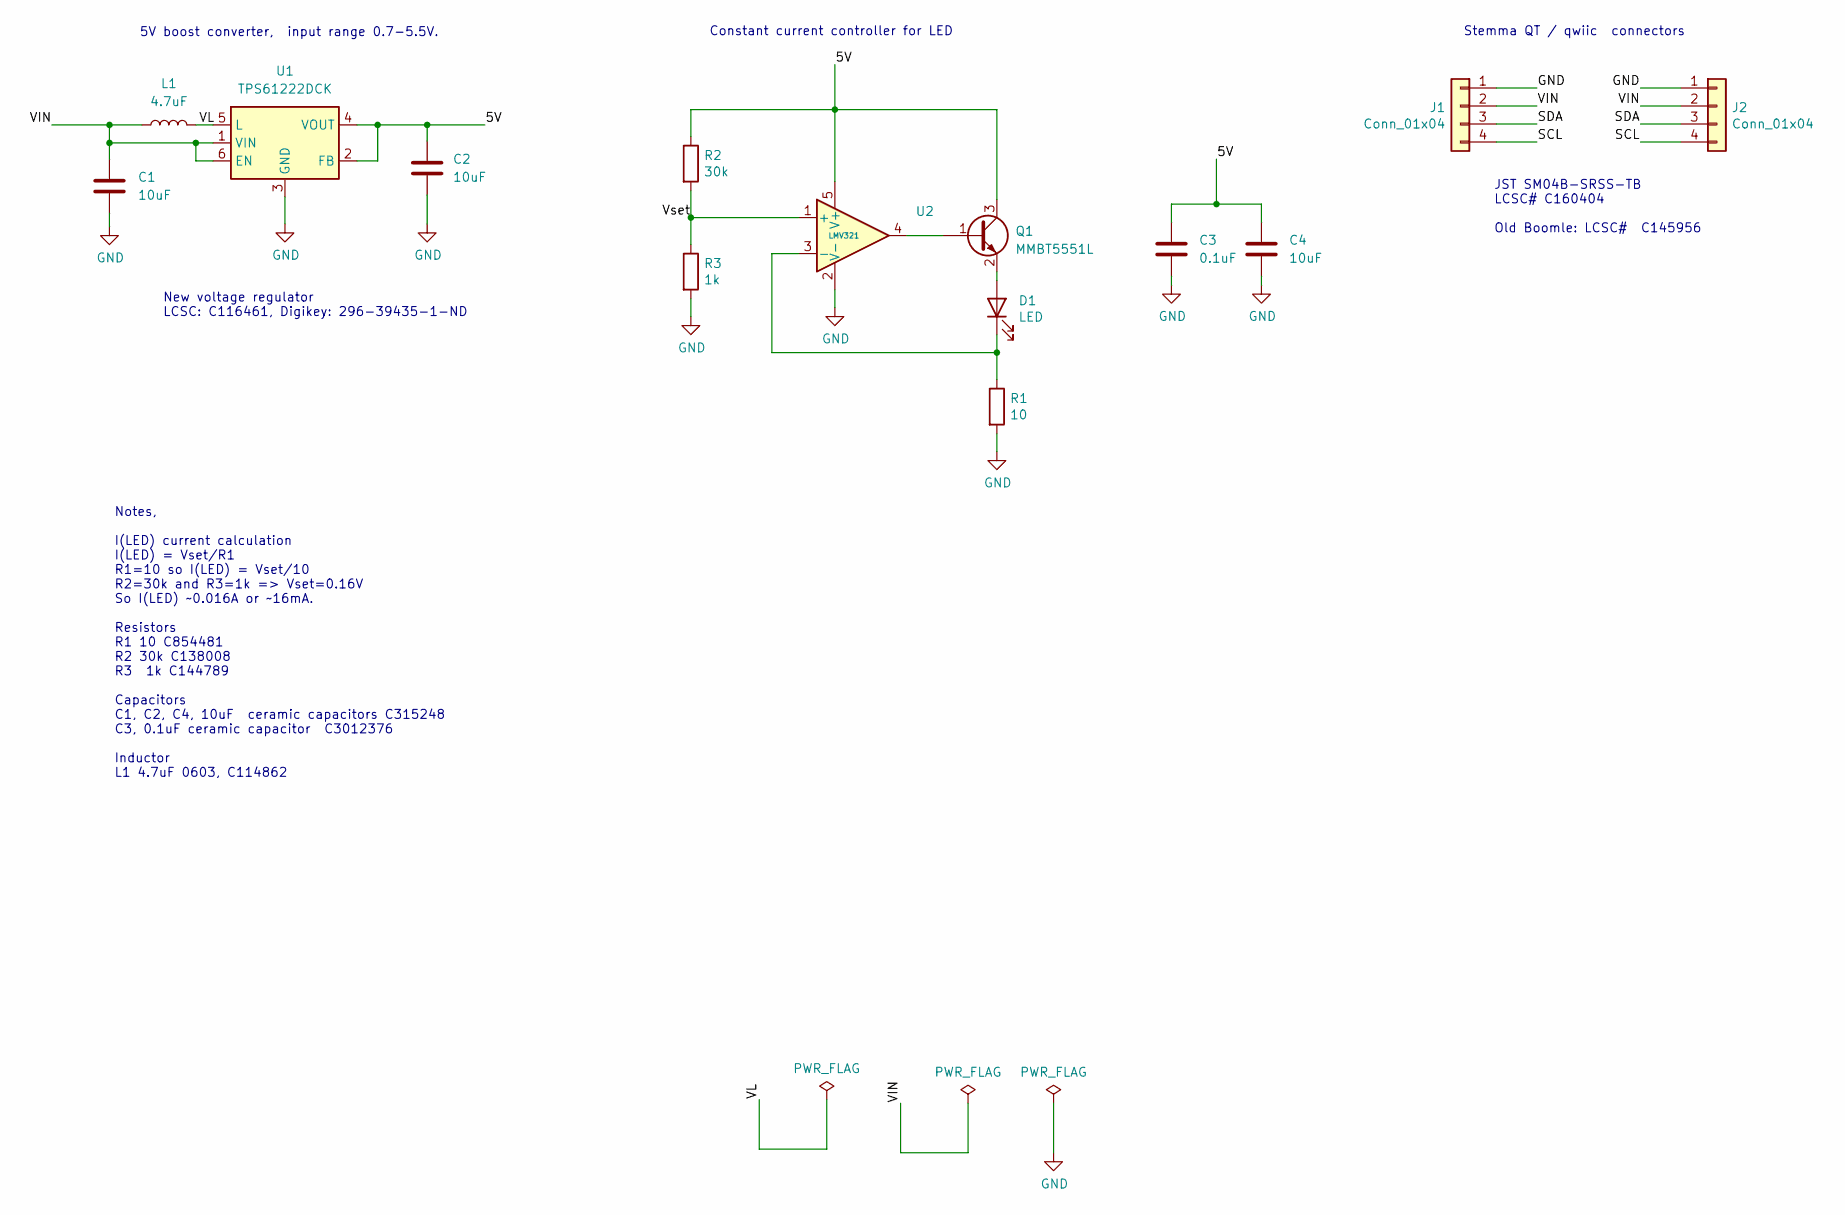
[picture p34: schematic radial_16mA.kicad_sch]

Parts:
C1, C2, C4: 10uF; C_0402_1005Metric
C3: 0.1uF; C_0402_1005Metric
D1: LED; LED_D3.0mm
J1, J2: Conn_01x04; JST_SH_SM04B-SRSS-TB_1x04-1MP_P1.00mm_Horizontal
L1: 4.7uF; L_0603_1608Metric
Q1: MMBT5551L; SOT-23
R1: 10; R_0402_1005Metric
R2: 30k; R_0402_1005Metric
R3: 1k; R_0402_1005Metric
U1: TPS61222DCK; SOT-363_SC-70-6
U2: LMV321; SOT-23-5

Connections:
/5V: C2.2, C3.1, C4.1, Q1.3 (C), R2.1, U1.2 (FB), U1.4 (VOUT), U2.5 (V+)
/SCL: J1.4, J2.4
/SDA: J1.3, J2.3
/VIN: C1.2, J1.2, J2.2, L1.1, U1.1 (VIN), U1.6 (EN)
/VL: L1.2, U1.5 (L)
/Vset: R2.2, R3.1, U2.1 (+)
GND: C1.1, C2.1, C3.2, C4.2, J1.1, J2.1, R1.2, R3.2, U1.3 (GND), U2.2 (V-)
unnamed: D1.2 (A), Q1.2 (E)
unnamed: D1.1 (K), R1.1, U2.3 (-)
unnamed: Q1.1 (B), U2.4

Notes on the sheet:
JST SM04B-SRSS-TB LCSC# C160404 Old Boomle: LCSC# C145956
Stemma QT / qwiic connectors
New voltage regulator LCSC: C116461, Digikey: 296-39435-1-ND
Constant current controller for LED
5V boost converter, input range 0.7-5.5V.
Notes, I(LED) current calculation I(LED) = Vset/R1 R1=10 so I(LED) = Vset/10 R2=30k and R3=1k => Vset=0.16V So I(LED) ~0.016A or ~16mA. Resistors R1 10 C854481 R2 30k C138008 R3 1k C144789 Capacitors C1, C2, C4, 10uF ceramic capacitors C315248 C3, 0.1uF ceramic capacitor C3012376 Inductor L1 4.7uF 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

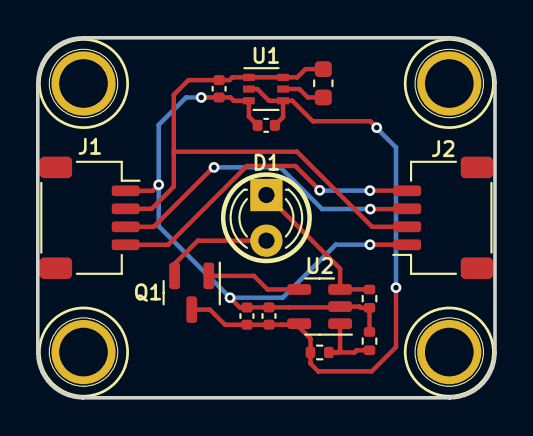
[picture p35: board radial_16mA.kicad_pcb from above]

Board: 2 copper layers, 25.4 x 20.0 mm, 18 parts (0 on the bottom side), 10 nets.

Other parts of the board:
M1, M2, M3, M4: MountingHole_2.5mm_Pad

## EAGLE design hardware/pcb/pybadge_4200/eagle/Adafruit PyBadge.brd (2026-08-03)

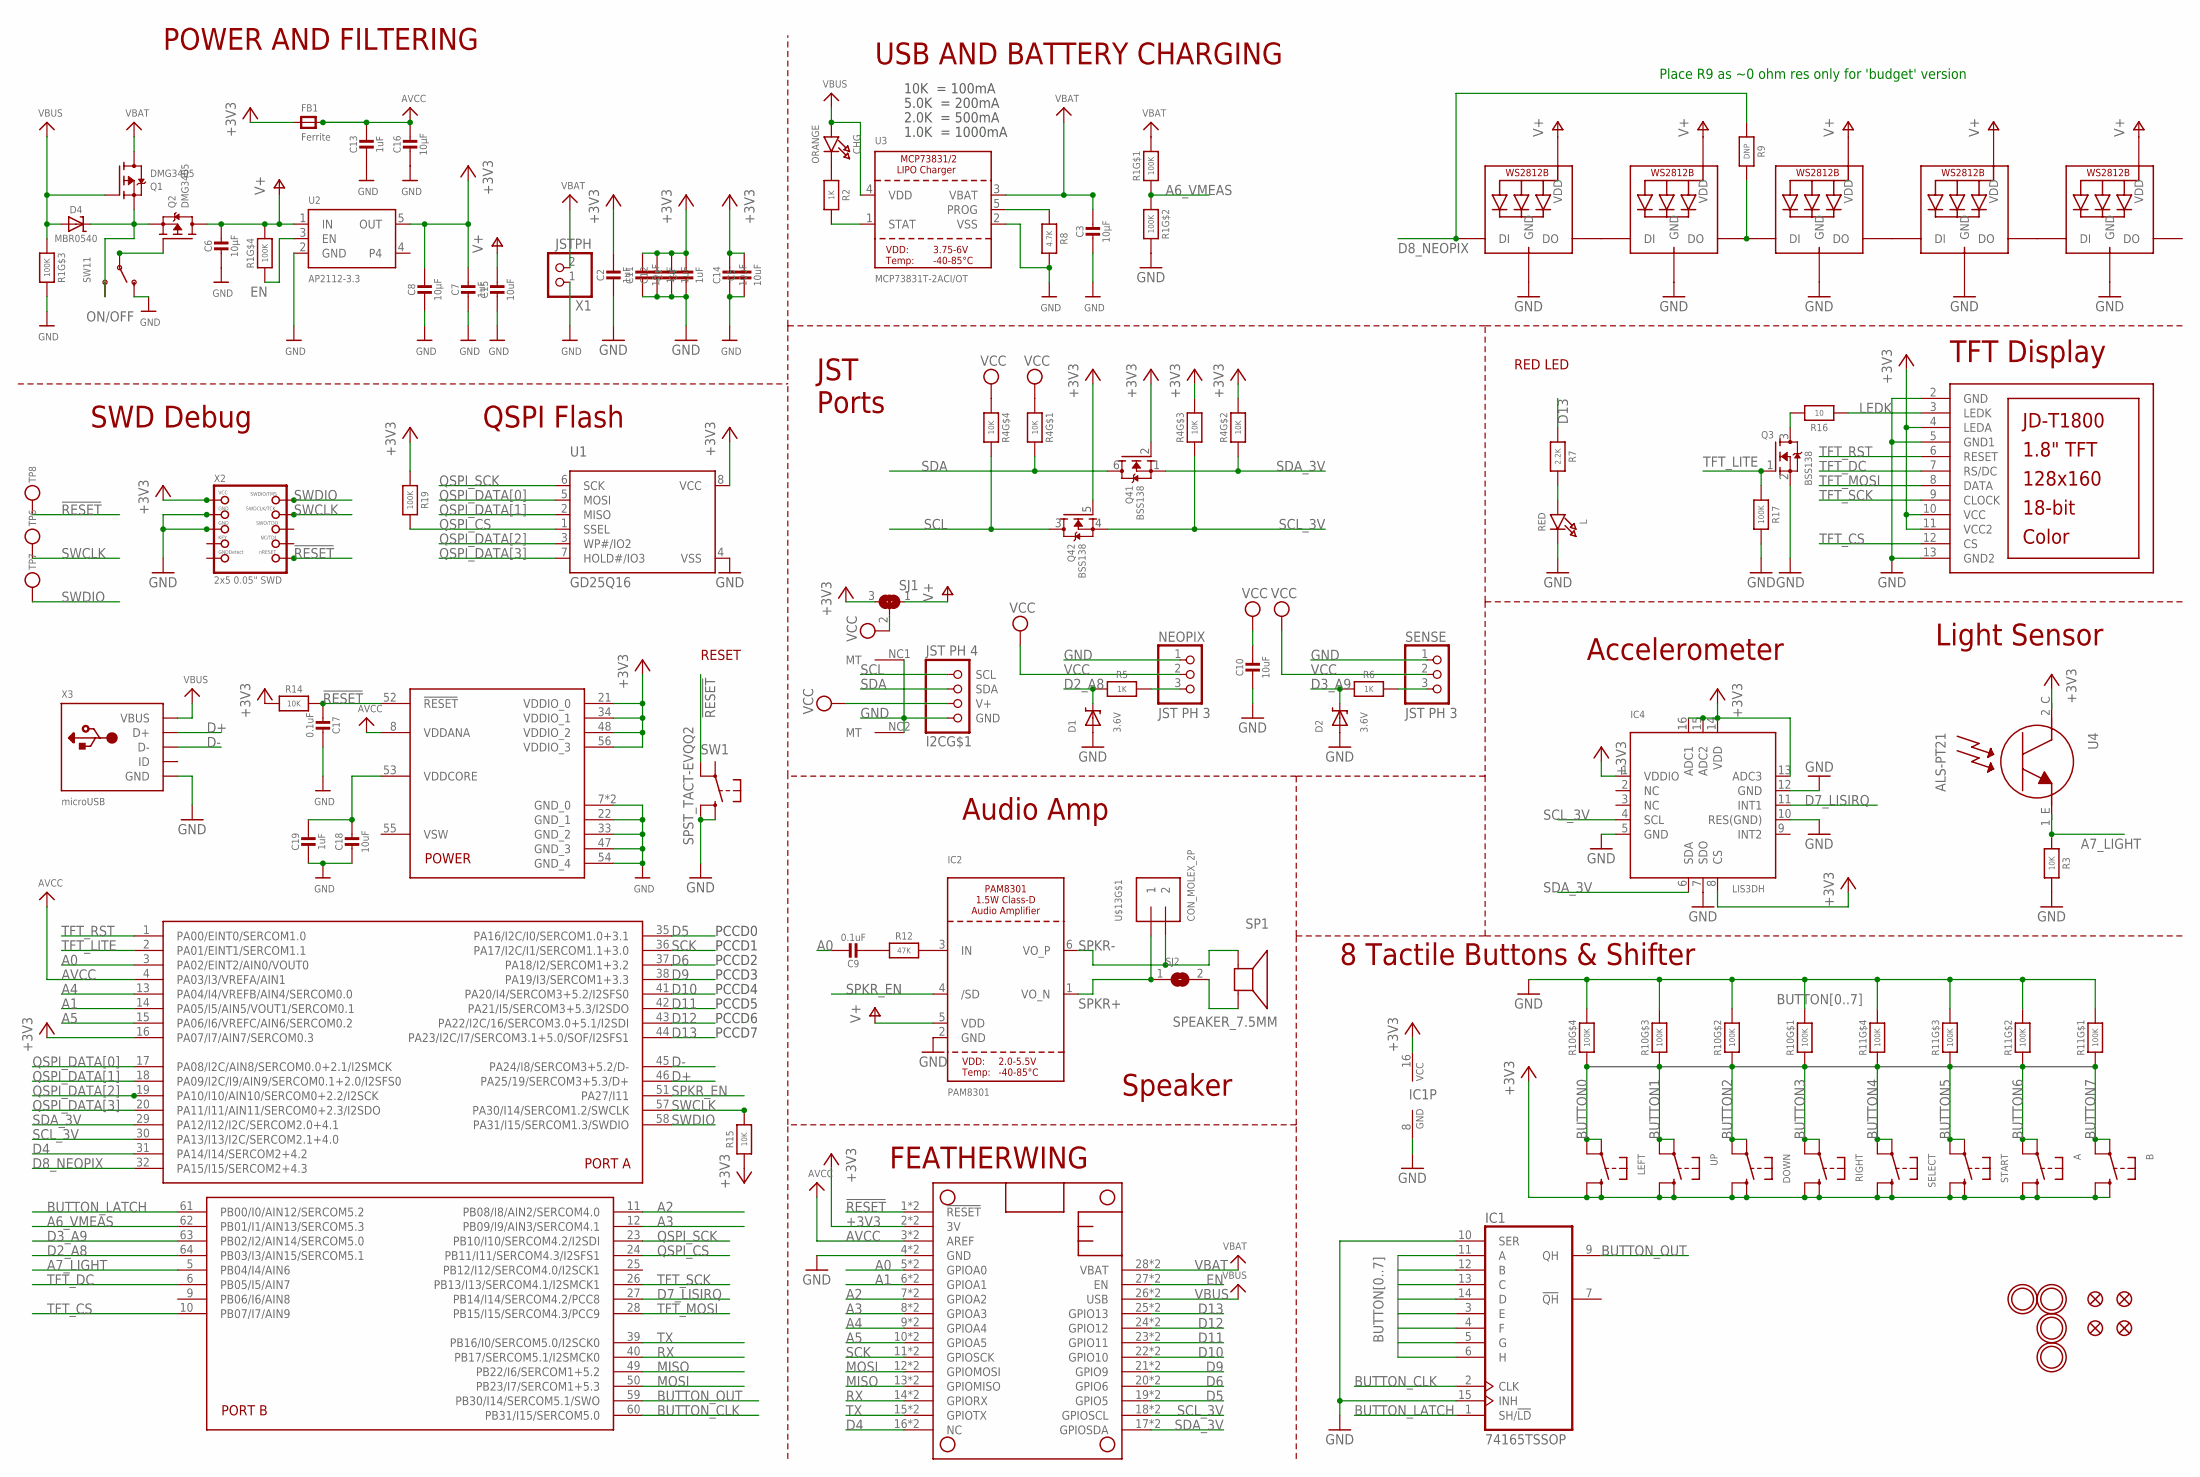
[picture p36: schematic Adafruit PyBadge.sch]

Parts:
A: SWITCH_TACT_SMT_6MMSMALL; 6MM_SMT
B: SWITCH_TACT_SMT_6MMSMALL; 6MM_SMT
C1, C2, C4, C7, C12, C13, C19: 1uF; 0603-NO
C3, C6, C8: 10µF; 0805-NO
C5, C10, C11, C14, C15, C18: 10uF; 0805-NO
C9, C17: 0.1uF; 0603-NO
C16: 10µF; _0805MP
CHG: ORANGE; CHIPLED_0805_NOOUTLINE
D1, D2: 3.6V; SOD-323
D4: MBR0540; SOD-123
DOWN: SWITCH_TACT_SMT_6MMSMALL; 6MM_SMT
FB1: Ferrite; 0805-NO
I2C: JST PH 4; JSTPH4
IC1: 74165TSSOP; TSSOP16
IC2: PAM8301; SOT23-6
IC4: LIS3DH; LGA16_3X3MM
L: RED; CHIPLED_0805_NOOUTLINE
LCD1: DISP_LCD_JDT1800; JD-T1800
LED1, LED2, LED3, LED4, LED5: WS2812B3535; LED3535
LEFT: SWITCH_TACT_SMT_6MMSMALL; 6MM_SMT
MS1: FEATHERWING_SMTDUALNOHOLES; FEATHERWING_SMT_NOHOLES
NEOPIX: JST PH 3; JSTPH3
Q1, Q2: DMG3405; SOT23-R
Q3: BSS138; SOT23-WIDE
Q4: BSS138; SOT363
R1, R10, R11: 100K; RESPACK_4X0603
R2, R5, R6: 1K; 0603-NO
R3, R14, R15: 10K; 0603-NO
R4: 10K; RESPACK_4X0603
R7: 2.2K; 0603-NO
R8: 4.7K; 0603-NO
R9: DNP; 0603-NO
R12: 47K; 0603-NO
R16: 10; 0603-NO
R17, R19: 100K; 0603-NO
RIGHT: SWITCH_TACT_SMT_6MMSMALL; 6MM_SMT
SELECT: SWITCH_TACT_SMT_6MMSMALL; 6MM_SMT
SENSE: JST PH 3; JSTPH3
SJ1: SOLDERJUMPER_2WAY; SOLDERJUMPER_2WAY_OPEN_NOPASTE
SJ2: SOLDERJUMPERCLOSED; SOLDERJUMPER_CLOSEDWIRE
SP1: SPEAKER_7.5MM; BUZZER_SMT_7.5MM
START: SWITCH_TACT_SMT_6MMSMALL; 6MM_SMT
SW1: SPST_TACT-EVQQ2; EVQ-Q2_SMALLER
SW11: SWITCH_SPDT; SPDT_SMT_SSSS811101
TP6, TP7, TP8: TESTPOINTROUND2MM; TESTPOINT_ROUND_2MM
U1: GD25Q16; SOIC8_208MIL
U2: AP2112-3.3; SOT23-5
U3: MCP73831T-2ACI/OT; SOT23-5
U4: ALS-PT21; ALS-PT26-21C
U$5, U$6, U$15, U$17: MOUNTINGHOLE3.0THIN; MOUNTINGHOLE_3.0_PLATEDTHIN
U$13: CON_MOLEX_2P; 53398-0271
U$24: ATSAMD51J19; PQFN64-1
U$34, U$35, U$42, U$43: FIDUCIAL_1MM
UP: SWITCH_TACT_SMT_6MMSMALL; 6MM_SMT
X1: JSTPH; JSTPH2
X2: 2x5 0.05" SWD; 2X05_1.27MM_BOX_POSTS
X3: microUSB; 4UCONN_20329_V2

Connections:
!RESET: C17.2, MS1.1 (!RESET), MS1.1B (!RESET), R14.2, SW1.A' (P1), TP8.P$1, U$24.52 (!RESET), X2.10 (NRESET)
+3V3: A.B (S), A.B' (S1), B.B (S), B.B' (S1), C1.1, C2.1, C4.1, C5.1, C7.1, C8.1, C11.1, C12.1, C14.1, DOWN.B (S), DOWN.B' (S1), FB1.1, IC1.16 (VCC), IC4.1 (VDDIO), IC4.8 (CS), IC4.13 (ADC3), IC4.14 (VDD), IC4.15 (ADC2), IC4.16 (ADC1), LCD1.4 (LEDA), LCD1.10 (VCC), LCD1.11 (VCC2), LEFT.B (S), LEFT.B' (S1), MS1.2 (3V), MS1.2B (3V), Q4.2 (G), Q4.5 (G), R4.2 (1), R4.3 (1), R14.1, R15.1, R19.1, RIGHT.B (S), RIGHT.B' (S1), SELECT.B (S), SELECT.B' (S1), SJ1.3, START.B (S), START.B' (S1), U1.8 (VCC), U2.5 (OUT), U4.2_C (C), U$24.16 (PA07/I7/AIN7/SERCOM0.3), U$24.21 (VDDIO_0), U$24.34 (VDDIO_1), U$24.48 (VDDIO_2), U$24.56 (VDDIO_3), UP.B (S), UP.B' (S1), X2.1 (VCC)
A0: C9.1, MS1.5 (GPIOA0), MS1.5B (GPIOA0), U$24.3 (PA02/EINT2/AIN0/VOUT0)
A1: MS1.6 (GPIOA1), MS1.6B (GPIOA1), U$24.14 (PA05/I5/AIN5/VOUT1/SERCOM0.1)
A2: MS1.7 (GPIOA2), MS1.7B (GPIOA2), U$24.11 (PB08/I8/AIN2/SERCOM4.0)
A3: MS1.8 (GPIOA3), MS1.8B (GPIOA3), U$24.12 (PB09/I9/AIN3/SERCOM4.1)
A4: MS1.9 (GPIOA4), MS1.9B (GPIOA4), U$24.13 (PA04/I4/VREFB/AIN4/SERCOM0.0)
A5: MS1.10 (GPIOA5), MS1.10B (GPIOA5), U$24.15 (PA06/I6/VREFC/AIN6/SERCOM0.2)
A6_VMEAS: R1.1, R1.2 (1), U$24.62 (PB01/I1/AIN13/SERCOM5.3)
A7_LIGHT: R3.2, U4.1_E (E), U$24.5 (PB04/I4/AIN6)
AVCC: C13.1, C16.1, FB1.2, MS1.3 (AREF), MS1.3B (AREF), U$24.4 (PA03/I3/VREFA/AIN1), U$24.8 (VDDANA)
BUTTON0: IC1.11 (A), LEFT.A, LEFT.A' (P1), R10.4 (1)
BUTTON1: IC1.12 (B), R10.3 (1), UP.A, UP.A' (P1)
BUTTON2: DOWN.A, DOWN.A' (P1), IC1.13 (C), R10.2 (1)
BUTTON3: IC1.14 (D), R10.1, RIGHT.A, RIGHT.A' (P1)
BUTTON4: IC1.3 (E), R11.4 (1), SELECT.A, SELECT.A' (P1)
BUTTON5: IC1.4 (F), R11.3 (1), START.A, START.A' (P1)
BUTTON6: A.A, A.A' (P1), IC1.5 (G), R11.2 (1)
BUTTON7: B.A, B.A' (P1), IC1.6 (H), R11.1
BUTTON_CLK: IC1.2 (CLK), U$24.60 (PB31/I15/SERCOM5.0)
BUTTON_LATCH: IC1.1 (SH/!LD), U$24.61 (PB00/I0/AIN12/SERCOM5.2)
BUTTON_OUT: IC1.9 (QH), U$24.59 (PB30/I14/SERCOM5.1/SWO)
CHG_LED: R2.2, U3.1 (STAT)
CHG_RATE: R8.1, U3.5 (PROG)
D2_: NEOPIX.3, R5.1
D2_A8: D1.C, R5.2, U$24.64 (PB03/I3/AIN15/SERCOM5.1)
D3_: R6.1, SENSE.3
D3_A9: D2.C, R6.2, U$24.63 (PB02/I2/AIN14/SERCOM5.0)
D4: MS1.16 (NC), MS1.16B (NC), U$24.31 (PA14/I14/SERCOM2+4.2)
D5: MS1.19 (GPIO5), MS1.19B (GPIO5), U$24.35 (PA16/I2C/I0/SERCOM1.0+3.1)
D6: MS1.20 (GPIO6), MS1.20B (GPIO6), U$24.37 (PA18/I2/SERCOM1+3.2)
D7_LISIRQ: IC4.11 (INT1), U$24.27 (PB14/I14/SERCOM4.2/PCC8)
D8_NEOPIX: LED1.1 (DI), R9.1, U$24.32 (PA15/I15/SERCOM2+4.3)
D9: MS1.21 (GPIO9), MS1.21B (GPIO9), U$24.38 (PA19/I3/SERCOM1+3.3)
D10: MS1.22 (GPIO10), MS1.22B (GPIO10), U$24.41 (PA20/I4/SERCOM3+5.2/I2SFS0)
D11: MS1.23 (GPIO11), MS1.23B (GPIO11), U$24.42 (PA21/I5/SERCOM3+5.3/I2SDO)
D12: MS1.24 (GPIO12), MS1.24B (GPIO12), U$24.43 (PA22/I2C/16/SERCOM3.0+5.1/I2SDI)
D13: MS1.25 (GPIO13), MS1.25B (GPIO13), R7.1, U$24.44 (PA23/I2C/I7/SERCOM3.1+5.0/SOF/I2SFS1)
D+: U$24.46 (PA25/19/SERCOM3+5.3/D+), X3.D+
D-: U$24.45 (PA24/I8/SERCOM3+5.2/D-), X3.D-
EN: MS1.27 (EN), MS1.27B (EN), R1.4 (1), U2.3 (EN)
GND: C1.2, C2.2, C3.2, C4.2, C5.2, C6.2, C7.2, C8.2, C10.2, C11.2, C12.2, C13.2, C14.2, C15.2, C16.2, C17.1, C18.2, C19.2, D1.A, D2.A, I2C.1 (GND), I2C.NC1 (MT), I2C.NC2 (MT), IC1.8 (GND), IC1.10 (SER), IC1.15 (INH), IC2.2 (GND), IC4.5 (GND), IC4.7 (SDO), IC4.10 (RES(GND)), IC4.12 (GND), L.C, LCD1.2 (GND), LCD1.5 (GND1), LCD1.13 (GND2), LED1.4 (GND), LED2.4 (GND), LED3.4 (GND), LED4.4 (GND), LED5.4 (GND), MS1.4 (GND), MS1.4B (GND), NEOPIX.1, Q3.2 (S), R1.6 (2), R1.7 (2), R3.1, R8.2, R10.5 (2), R10.6 (2), R10.7 (2), R10.8 (2), R11.5 (2), R11.6 (2), R11.7 (2), R11.8 (2), R17.2, SENSE.1, SW1.B (S), SW1.B' (S1), SW11.A (O), U1.4 (VSS), U2.2 (GND), U3.2 (VSS), U$24.7 (GND_0), U$24.22 (GND_1), U$24.33 (GND_2), U$24.47 (GND_3), U$24.54 (GND_4), U$24.EXP (GND_0), X1.1, X2.3 (GND), X2.5 (GND), X3.BASE@1 (GND), X3.BASE@2 (GND), X3.GND, X3.SPRT@1 (GND), X3.SPRT@2 (GND), X3.SPRT@3 (GND), X3.SPRT@4 (GND)
LEDK: LCD1.3 (LEDK), R16.1
MISO: MS1.13 (GPIOMISO), MS1.13B (GPIOMISO), U$24.49 (PB22/I6/SERCOM1+5.2)
MOSI: MS1.12 (GPIOMOSI), MS1.12B (GPIOMOSI), U$24.50 (PB23/I7/SERCOM1+5.3)
unnamed: CHG.C, R2.1
unnamed: L.A, R7.2
unnamed: LED1.3 (DO), LED2.1 (DI)
unnamed: LED2.3 (DO), LED3.1 (DI), R9.2
unnamed: LED3.3 (DO), LED4.1 (DI)
unnamed: Q3.3 (D), R16.2
unnamed: LED4.3 (DO), LED5.1 (DI)
unnamed: D4.C, Q1.2 (S), Q2.2 (S), SW11.C (S)
unnamed: C9.2, R12.1
unnamed: IC2.3 (IN), R12.2
unnamed: SJ2.2, SP1.-
ON/OFF: Q2.1 (G), SW11.B
QSPI_CS: R19.2, U1.1 (SSEL), U$24.24 (PB11/I11/SERCOM4.3/I2SFS1)
QSPI_DATA[0]: U1.5 (MOSI), U$24.17 (PA08/I2C/AIN8/SERCOM0.0+2.1/I2SMCK)
QSPI_DATA[1]: U1.2 (MISO), U$24.18 (PA09/I2C/I9/AIN9/SERCOM0.1+2.0/I2SFS0)
QSPI_DATA[2]: U1.3 (WP#/IO2), U$24.19 (PA10/I10/AIN10/SERCOM0+2.2/I2SCK)
QSPI_DATA[3]: U1.7 (HOLD#/IO3), U$24.20 (PA11/I11/AIN11/SERCOM0+2.3/I2SDO)
QSPI_SCK: U1.6 (SCK), U$24.23 (PB10/I10/SERCOM4.2/I2SDI)
RX: MS1.14 (GPIORX), MS1.14B (GPIORX), U$24.40 (PB17/SERCOM5.1/I2SMCK0)
SCK: MS1.11 (GPIOSCK), MS1.11B (GPIOSCK), U$24.36 (PA17/I2C/I1/SERCOM1.1+3.0)
SCL: I2C.4 (SCL), Q4.3 (D), R4.5 (2)
SCL_3V: IC4.4 (SCL), MS1.18 (GPIOSCL), MS1.18B (GPIOSCL), Q4.4 (S), R4.6 (2), U$24.30 (PA13/I13/I2C/SERCOM2.1+4.0)
SDA: I2C.3 (SDA), Q4.6 (D), R4.8 (2)
SDA_3V: IC4.6 (SDA), MS1.17 (GPIOSDA), MS1.17B (GPIOSDA), Q4.1 (S), R4.7 (2), U$24.29 (PA12/I12/I2C/SERCOM2.0+4.1)
SPKR+: IC2.1 (VO_N), SJ2.1, U$13.1
SPKR-: IC2.6 (VO_P), SP1.+, U$13.2
SPKR_EN: IC2.4 (/SD), U$24.51 (PA27/I11)
SWCLK: R15.2, TP6.P$1, U$24.57 (PA30/I14/SERCOM1.2/SWCLK), X2.4 (SWDCLK)
SWDIO: TP7.P$1, U$24.58 (PA31/I15/SERCOM1.3/SWDIO), X2.2 (SWDIO)
TFT_CS: LCD1.12 (CS), U$24.10 (PB07/I7/AIN9)
TFT_DC: LCD1.7 (RS/DC), U$24.6 (PB05/I5/AIN7)
TFT_LITE: Q3.1 (G), R17.1, U$24.2 (PA01/EINT1/SERCOM1.1)
TFT_MOSI: LCD1.8 (DATA), U$24.28 (PB15/I15/SERCOM4.3/PCC9)
TFT_RST: LCD1.6 (RESET), U$24.1 (PA00/EINT0/SERCOM1.0)
TFT_SCK: LCD1.9 (CLOCK), U$24.26 (PB13/I13/SERCOM4.1/I2SMCK1)
TX: MS1.15 (GPIOTX), MS1.15B (GPIOTX), U$24.39 (PB16/I0/SERCOM5.0/I2SCK0)
V+: C6.1, C15.1, IC2.5 (VDD), LED1.2 (VDD), LED2.2 (VDD), LED3.2 (VDD), LED4.2 (VDD), LED5.2 (VDD), Q2.3 (D), R1.5 (2), SJ1.1, U2.1 (IN)
VBAT: C3.1, MS1.28 (VBAT), MS1.28B (VBAT), Q1.3 (D), R1.8 (2), U3.3 (VBAT), X1.2
VBUS: CHG.A, D4.A, MS1.26 (USB), MS1.26B (USB), Q1.1 (G), R1.3 (1), U3.4 (VDD), X3.VBUS
VCC: C10.1, I2C.2 (V+), NEOPIX.2, R4.1, R4.4 (1), SENSE.2, SJ1.2
VDDCORE2: C18.1, C19.1, U$24.53 (VDDCORE)

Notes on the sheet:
POWER AND FILTERING
RESET
10K = 100mA
5.0K = 200mA
2.0K = 500mA
1.0K = 1000mA
USB AND BATTERY CHARGING
RED LED
Accelerometer
Light Sensor
FEATHERWING
TFT Display
Audio Amp
JST Ports
PCCD0
PCCD1
PCCD2
PCCD3
PCCD4
PCCD5
PCCD6
PCCD7
Speaker
Place R9 as ~0 ohm res only for 'budget' version
8 Tactile Buttons & Shifter
SWD Debug
QSPI Flash

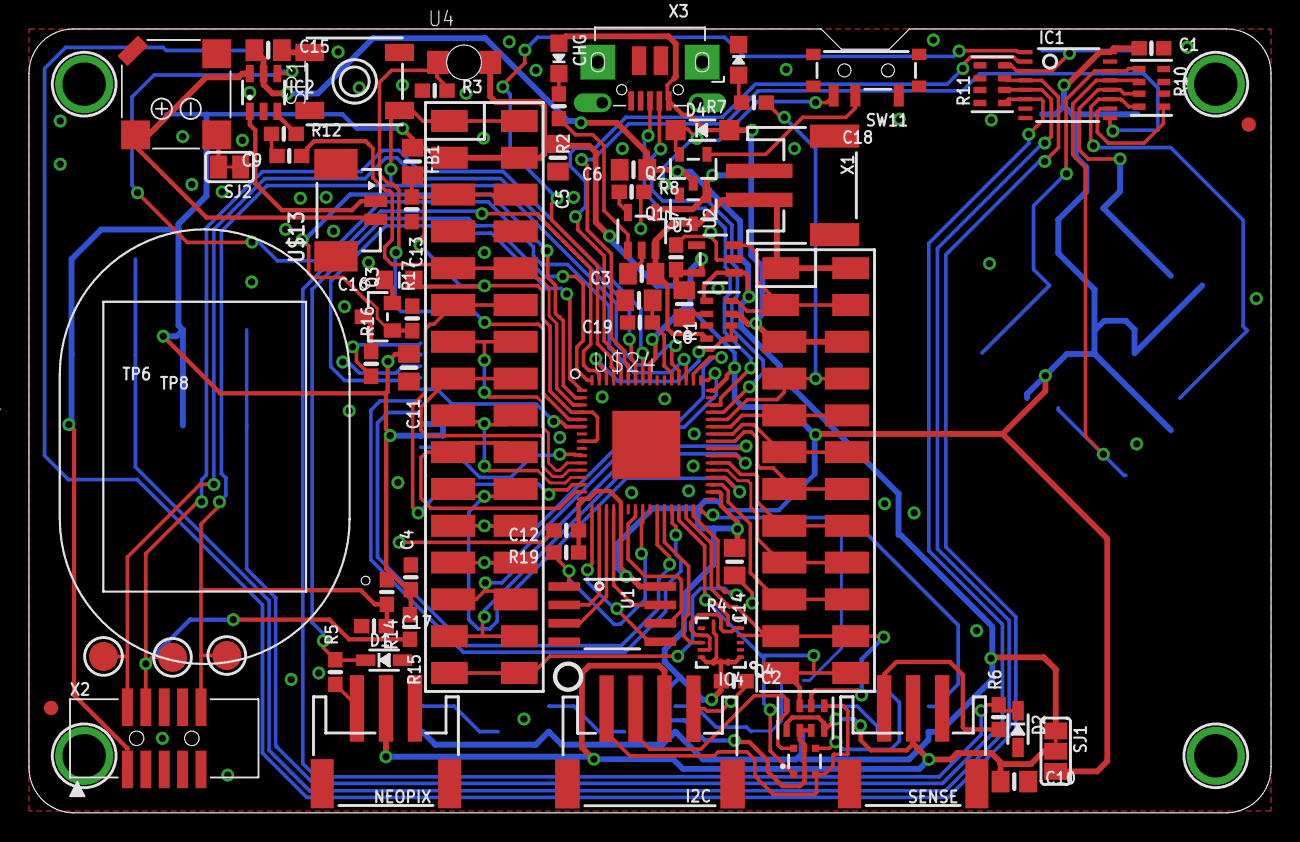
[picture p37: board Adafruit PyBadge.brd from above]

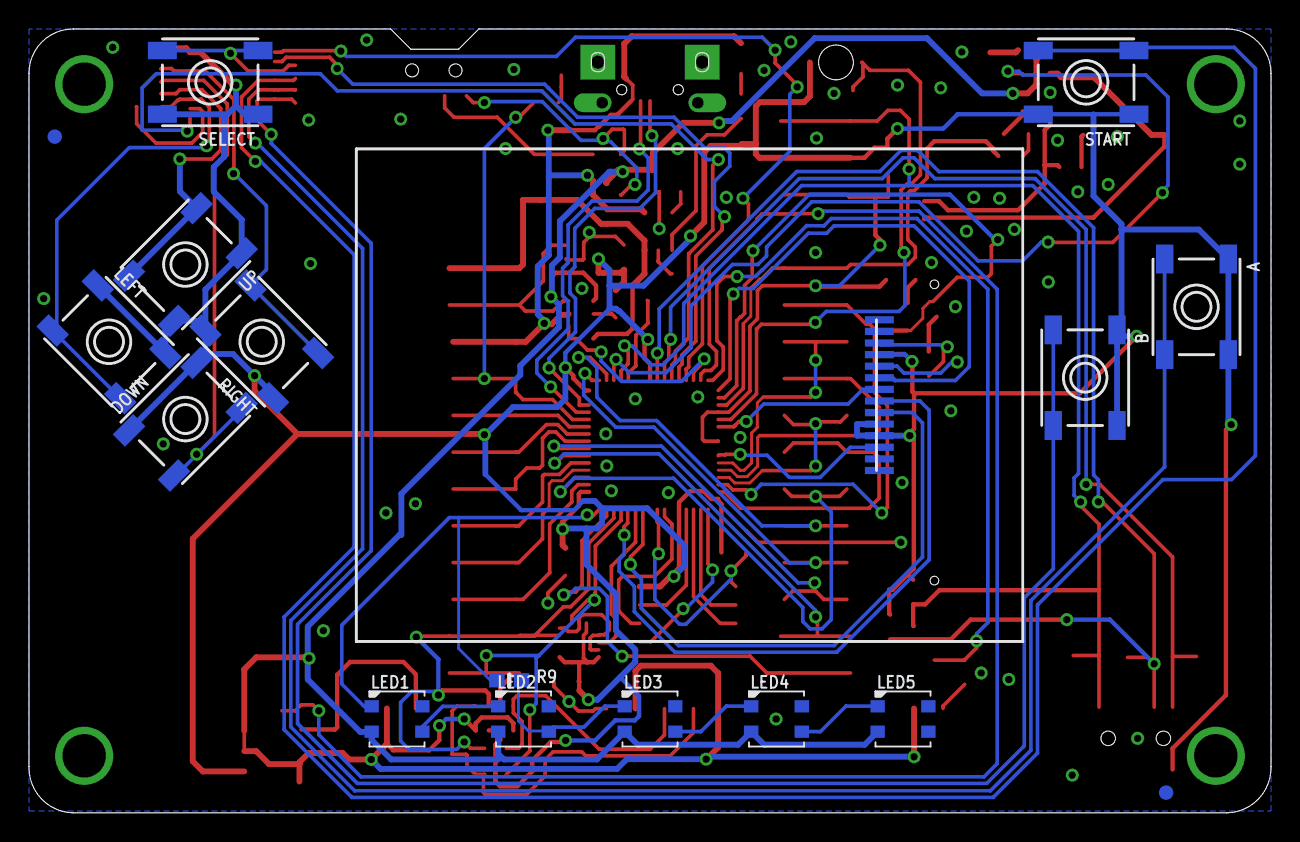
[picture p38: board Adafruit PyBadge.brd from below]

Board: 2 copper layers, 85.7 x 54.1 mm, 96 parts (18 on the bottom side), 86 nets.

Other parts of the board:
U$8: SPEAKER_OVAL8OHM
U$18: PYBADGE_TOP
U$32: PYBADGE_BOT
U$37: PCBFEAT-REV-040

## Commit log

2026-08-02 Initial repository structure v0.1.2-draft.1
    [alternates.csv, cost_history.csv, master_bom.csv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]
2026-08-02 Refine README with project name and sensor details
    Updated project name placeholder and clarified sensor description.
2026-08-02 new chapter - theory
    [source_register.csv]
2026-08-02 Fix calibration description in README.md
2026-08-03 Add draft hardware and assembly documentation
    [Adafruit_PyBadge.brd, Adafruit_PyBadge.sch, BOM_JLCPCB_radial_16mA.xlsx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]
2026-08-03 Update README with hardware and assembly documentation
    Added draft hardware and assembly documentation to the README.
2026-08-03 Specify dimensions for excitation and emission filters
    Updated the dimensions of the excitation and emission filters in the optical architecture section.
2026-08-03 Add PyBadge bootloader updater and installation files
    Add the PyBadge bootloader v3.15.0 UF2 updater and retain the raw BIN
    image for archival and recovery purposes.
    Update the CircuitPython and firmware installation documentation,
    checksums, manifests, third-party notices, and workshop booklet
    chapter.
    [Adafruit PyBadge.brd, Adafruit PyBadge.sch, BOM_JLCPCB_radial_16mA.xlsx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]
2026-08-03 Replace navigation figure with corrected control map
    Replace the previous draft navigation image with the corrected front-panel
    control map for the DIY-QuantiFluorONE-dsDNA-Fluorometer.
    Update the chapter 05 figure reference and text so that the reset access
    opening and underside reset-button location are described correctly.
2026-08-03 not necessary anymore
    [PROVISIONAL_SOURCE_DATA.csv, quantifluorone_log_v052.csv, quantifluorone_log_v060.csv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]
2026-08-04 Fix image paths in hardware and assembly documentation
    Updated image paths for CAD overviews in the documentation.
2026-08-04 Fix image path in hardware and assembly documentation
    Updated image path for the assembled DIY-QuantiFluorONE prototype.
2026-08-05 validation: add Chapter 10 performance verification
    [blank_performance_summary.csv, diy_triplicate_concentration_summary.csv, quantifluorone_log_v100rc2.csv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]
2026-08-05 Fix formatting of calibration equation and R-squared
    Corrected formatting of the equation and R-squared value for clarity.
2026-08-05 Refactor equations to LaTeX format in documentation
    Updated mathematical expressions for DIY fluorometer calibration and analytical signal calculations to use LaTeX formatting. Improved clarity and consistency in the presentation of results.
2026-08-05 not necessary - cleanup of repo
    [Adafruit_PyBadge.brd, Adafruit_PyBadge.sch, BOM_JLCPCB_radial_16mA.xlsx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]
2026-08-05 Consolidate calibration suite under software
2026-08-05 Consolidate calibration suite under software - cleanup empty folder tools
2026-08-05 One directory contains all mechanical CAD models required
    [A_Main_Body_modified.stl, B_Excitation_Housing_modified.stl, C_Emission_Housing_modified.stl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]
2026-08-05 Description for 3D-parts of the diy-fluorometer
    [E_LED_Board_holder_alternative.stl]
2026-08-05 Consolidate mechanical CAD models
2026-08-05 Consolidate third-party PCB source files
    [Adafruit PyBadge.brd, Adafruit PyBadge.sch, Adafruit_PyBadge.brd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]
2026-08-05 moving files
    [BOM_JLCPCB_radial_16mA.xlsx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]
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2026-08-06 new step files
    [A_Main_Body_modified_v13.step, C_Emission_Housing_modified_v3.step, E_LED_Board_holder_alternative.step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]
2026-08-06 file added
    [B_Excitation_Housing_modified.step]
2026-08-06 new entry
    [BOM_JLCPCB_radial_16mA.xlsx]
2026-08-06 Remove duplicate CAD figure variants
2026-08-06 content of chapter 03 revised
    [figure_manifest.csv]
2026-08-06 Update heading format in calibration results document
2026-08-06 Update formatting and headings in calibration documentation
2026-08-06 Complete Chapter 4 hardware photographs and assembly documentation
    - add excitation-side, detection-side, wiring and complete setup
    photographs
    - update Chapter 4 figure references and captions
    - remove completed photograph items from the open hardware list
    - update figure manifest
    [figure_manifest.csv]
2026-08-07 New part number added
    [BOM_JLCPCB_radial_16mA.xlsx]
2026-08-09 restructering pcb folder from iorodeo 16mA radial led-board
    [BOM_JLCPCB_radial_16mA.xlsx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]
2026-08-09 new consistent structure and numberin. deletion of wrong notes. actual version: current status: validated
2026-08-10 PROVISIONAL removed
    [quantus_diy_comparison_dataset.csv]
2026-08-10 Prepare repository for v1.0.0 release
    [assembly_hardware_tbd.csv, master_bom.csv]
2026-08-12 New version of calibration suite
2026-08-12 new calibration suite v7.3 and new release
    [Testdata_TOC_DIN38402-51.csv, calibration_MP_20260724_replicates.csv]
2026-08-13 Restructuring the Repo
    [PROVISIONAL_calibration_MP_2026-07-24.csv, blank_performance_summary.csv, diy_triplicate_concentration_summary.csv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]
2026-08-13 Restructuring Tree formatting csv to comma
    [quantus_diy_comparison_dataset.csv, quantus_diy_two_point_comparison.csv, quantusquantus_diy_two_point_comparison.csv]
2026-08-13 empty files removed
    [alternates.csv, assembly_hardware_tbd.csv, cost_history.csv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]
2026-08-14 reduction of cad picture size
2026-08-14 Adding sample list editing
2026-08-16 New design for LED-holder
    [LED Board + Vial Halter.step]
2026-08-20 new design for base plate holes fitting to screws
    [A_Main_Body_modified_v13.step]
2026-08-20 New step files added
    [B_Excitation_Housing_modified.step, E_LED Board + Vial Halter.step]
2026-09-09 Add EUR-Price column to master BOM
    Updated BOM to include EUR-Price column and adjusted item entries.
2026-09-09 Add EU-costs column to master BOM
    Added EU-costs column to BOM with pricing details.
2026-09-09 Modify quantities and notes in master BOM
    Updated quantities and notes for sample vessel, cable, and adapter.
2026-10-25 wird ersetzt mit update

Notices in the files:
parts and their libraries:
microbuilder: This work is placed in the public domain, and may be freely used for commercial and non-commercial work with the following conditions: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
